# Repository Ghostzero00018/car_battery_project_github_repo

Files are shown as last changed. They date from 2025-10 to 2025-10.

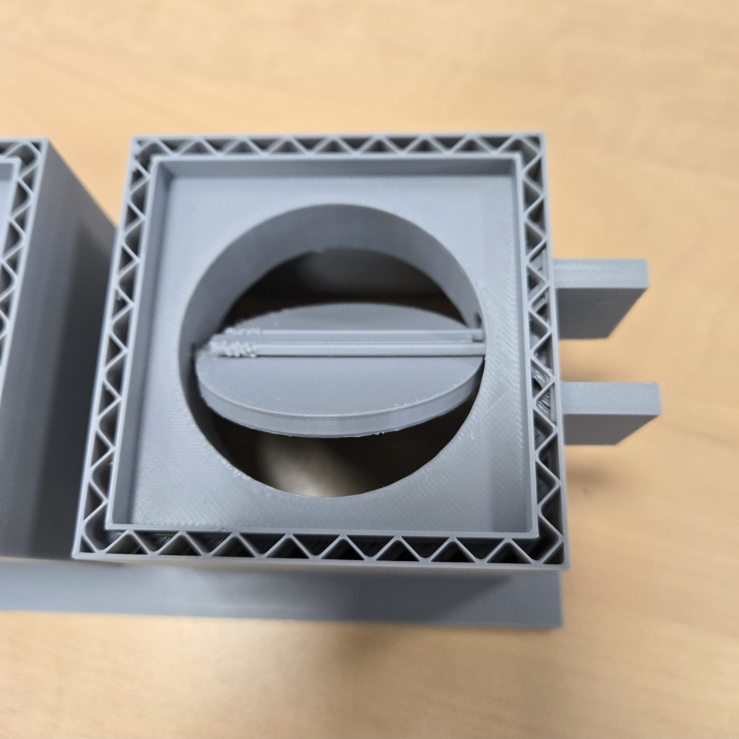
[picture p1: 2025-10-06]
docs/Report/Pics&Figs/Real_3D_print_parts_pics/Valve_system_with_servo_mount.jpg

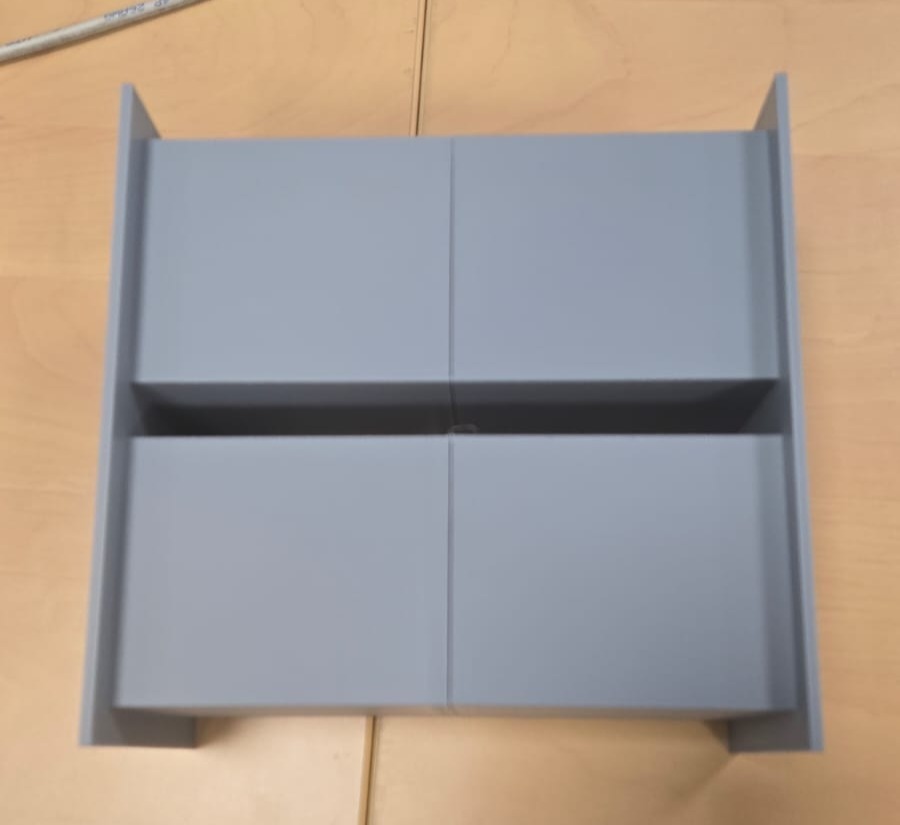
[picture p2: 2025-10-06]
docs/Report/Pics&Figs/Real_3D_print_parts_pics/docking_mechanism.jpg

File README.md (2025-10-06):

# Cascade Temperature Control with Smart Air Flow  

## NOT THE FINAL VERSION

## IMT Nord Europe — DNM–DMI 2025–2026

A compact **thermal control project** combining simulation, control design, and embedded implementation.  
The goal: heat and dry a coated metal plate in a small **8 L hotbox** while keeping air ≤ 70 °C (but higher than 60 °C) for safety.

---

## 🔍 Overview

- **Thermal model:** air, wall, and product (1-D conduction + radiation)  
- **Control:** cascade PI/PID loops  
  - Outer PI: core → air set-point  
  - Inner PID: air → heater power  
- **Airflow system:** fan + valves managed by a smart supervisor (heat-up / hold / safety)  
- **Embedded version:** MicroPython control on **Raspberry Pi Pico W** driving a hobby servo

---

## 🧠 Key Features

- Safe and stable heating control with power/temperature caps  
- Anti-windup, rate-limiting, and derivative filtering  
- Realistic airflow simulation (Δp PI and orifice flow)  
- Ready-to-run **MicroPython demo** — no Wi-Fi required  
- Fully documented **LaTeX report** with cross-references and figures

---

## ⚙️ Hardware Setup

| Component | Role |
|---|---|
| Raspberry Pi Pico W | Controller board |
| Hobby servo (5 V) | Air valve actuator |
| Temperature sensor | Internal ADC or NTC |
| Heater + Fan | Thermal actuation system |

> Servo signal → **GP1**, powered from 5 V (share GND with Pico)

---

## 💻 Quick Start

1. Flash **MicroPython** on the Pico W  
2. Upload `pico_thermostat_servo.py`  
3. Power the servo (5 V + GND) and run the script  
4. Monitor live telemetry

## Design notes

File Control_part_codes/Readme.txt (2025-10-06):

For all the codes in this folder I use Thonny as the IDE to write codes for Raspberry Pi Pico W.

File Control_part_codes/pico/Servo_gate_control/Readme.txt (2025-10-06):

In this folder the codes are mainly focused on the control of the servo, and the servo is used to control the open and close of the gate in this project.
In case you don't know what the gate is for, you can simply consider it as the valve that control whether the air enters the box, and if the air does enter, the air flow rate.
There are 4 versions of the code, each of them are using PID control. You can run on your Raspberry board to see the difference.

To test the code you need some basic hardwares: 1 basic Raspberry board (for example I use Raspberry Pi Pico W in this case, and don't forget about the USB cable so you can connect it to your PC); a breadboard to simplify the wiring; some wires of jumpers; a 5V power source.

The reason I use 5V power source is that if you use the 3.3V voltage that the Raspberry board provided, usually it is not enough to power up even the mini servo motor you can find on the market.

About the detialed wiring, you can check on this link: https://picozero.readthedocs.io/en/latest/recipes.html#servo; pay attention even as shown on the website, probably you still need a 5V power source rather than simply connect the servo to your Raspberry board.

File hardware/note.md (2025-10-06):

# notes.md — Working Notes & Operating Tips

Version: 0.1 (draft)

These notes capture practical tips, gotchas, and short procedures for the **hot-box battery thermal control** prototype.

## NOT THE FINAL VERSION

## 1) Safety First (must-read)

- **Heater fuse & thermal cutoff**: verify correct rating before any test.
- **Never** run the heater unattended on first bring-up. Keep a temp probe + fire extinguisher nearby.
- Ensure **fan spins** before enabling high heater duty. If fan fails, controller should **FAULT** (heater off).
- Keep sensor wiring & tubing away from **hot surfaces** and **12 V power** runs.

---

## 2) Power-On Checklist (short)

1. Visual check: polarity, MOSFET orientation, TVS direction, fuse values.
2. Power rails: 12 V, then 5 V (if used), confirm Pico **3.3 V**.
3. Flash firmware that starts **PWM = 0** and checks sensors.
4. Verify sensors:
   - DS18B20: detect all addresses, read sane values (20–35 °C at room).
   - dP sensor (I²C): show zero-ish Δp with open ports.
5. Fan test: 20% → 50% PWM; confirm airflow & current draw.
6. Heater test: start at 10–20% duty, watch temperature rise & MOSFET case temp.

---

## 3) Quick Calibration Hints

- **DS18B20**: place all sensors together at room temp → record offsets; repeat in warm environment (~40–50 °C).
- **Differential pressure**: with both ports vented together, record zero offset; use short, equal-length tubes.
- **Heater power**: measure 12 V and current with a clamp meter → P ≈ V·I at several PWM levels; note nonlinearity.

---

## 4) Logging & File Hygiene

- Log at least: `time, T_in, T_out, T_surface, PWM_fan, PWM_heater, dP, state, faults`.
- Save runs to `data/yyyy-mm-dd_testname.csv`.  
- Keep large logs out of Git history if they’re huge; consider **Git LFS** or add `data/` to `.gitignore`.

---

## 5) Control Tuning Notes

- Start with **PI** on heater loop; add small **D** only if overshoot persists.
- Use **soft-start**: ramp heater duty over 10–30 s to reduce overshoot.
- If oscillation occurs:
  - Reduce I-gain, add output **slew limit**, or increase fan flow for more **h**.
- Prefer **fixed airflow** for first tests; add supervisory fan control later.

---

## 6) Airflow & Leak Tests

- Prepare **interchangeable orifice inserts** (e.g., Ø2, 3, 4, 6, 8, 10 mm). Label each plate.
- For each orifice size: record steady **Δp**, estimated **Q**, warm-up time, steady power.
- Compare **single-hole + leak** vs **side vent** configurations under the same setpoint.

---

## 7) Common Pitfalls

- **Public repo ≠ write access**: collaborators need to be added on GitHub to push.
- **.gitignore not retroactive**: run `git rm -r --cached .` if you added it late.
- **BLDC fan flyback diode**: don’t add one; use **TVS** on the 12 V rail instead.
- **Noisy sensors** near heater cables: reroute, twist pairs, add small RC at MCU side.

---

## 8) Naming & Units (please stick to these)

- Temperatures: °C; Ambient `T_e`, Air `T_in`, `T_out`, Surface `T_s`.
- Power: W; Duty cycle: 0–100%.
- Pressure: Pa (Δp); Flow: m³/h (log both Δp and PWM; compute Q offline).
- Files: `sim/`, `control/`, `hardware/`, `docs/`, `data/`.

---

## 9) Branch & Changes (lightweight policy)

- Protect `main`; develop on feature branches.
- Use PRs with short descriptions: **why** + **what changed** + **how tested**.
- Tag key milestones (`v0.1-sim`, `v0.2-proto`).

---

## 10) TODO (next steps)

- [ ] Finalize exact Sunon fan P/N and add curve snapshot to `docs/`.
- [ ] Pick dP sensor range (±125 Pa vs ±500 Pa) and wire to I²C.
- [ ] Implement **state machine** (IDLE → PREHEAT → HOLD → FAULT).
- [ ] Add over-temp & sensor-timeout failsafes.
- [ ] Run first **setpoint sweep** (40, 50, 60 °C) and compare with simulation.

---

### Change Log

- **0.1** — Initial working notes added.

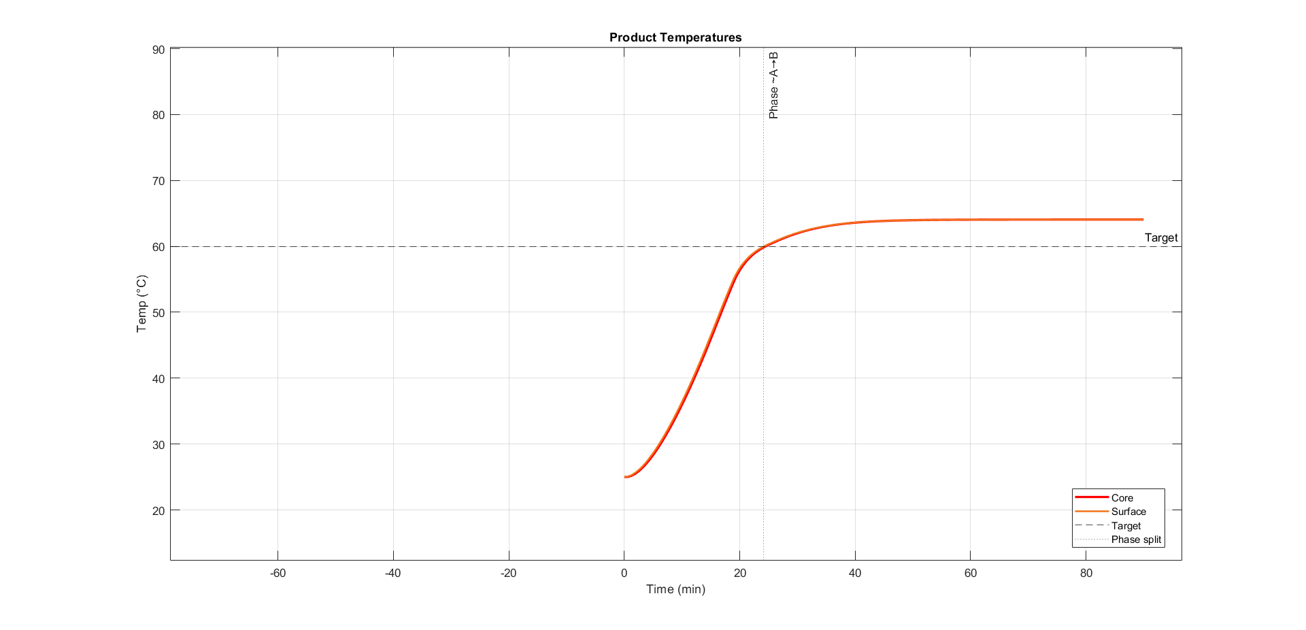
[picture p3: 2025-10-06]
docs/Report/Pics&Figs/Matlab_figs/fig_product_temps.png

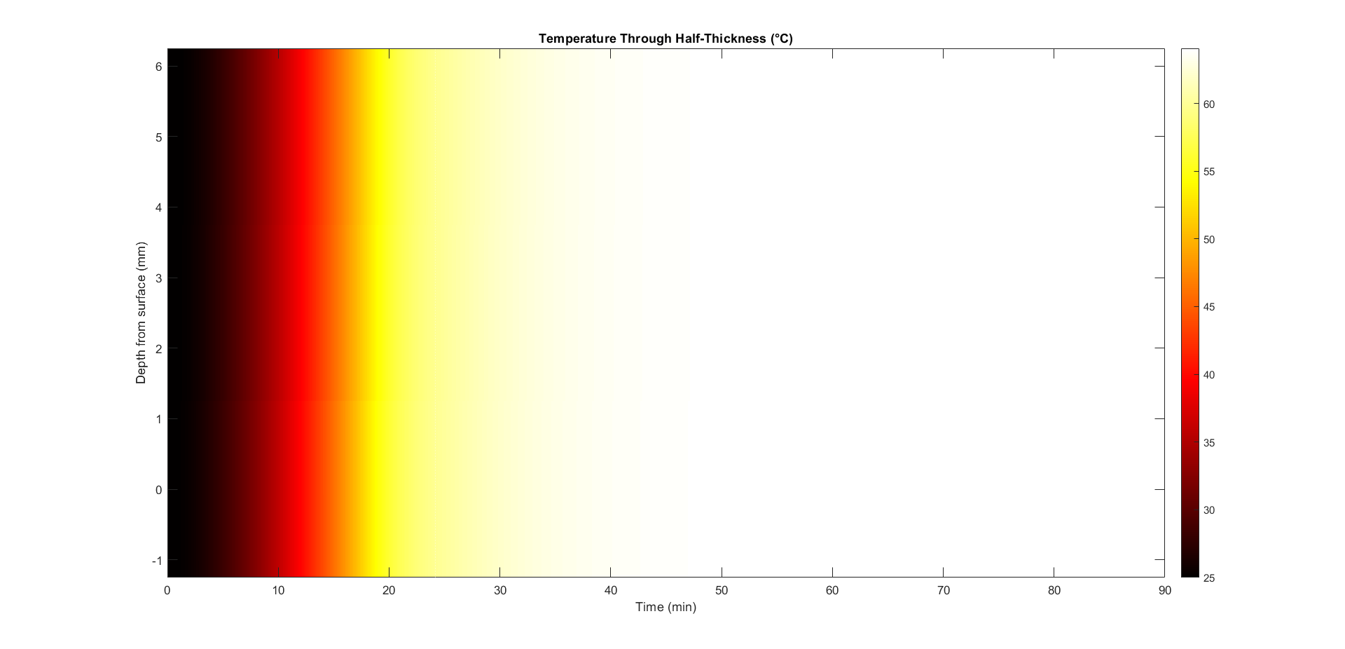
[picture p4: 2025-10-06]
docs/Report/Pics&Figs/Matlab_figs/fig_heatmap.png

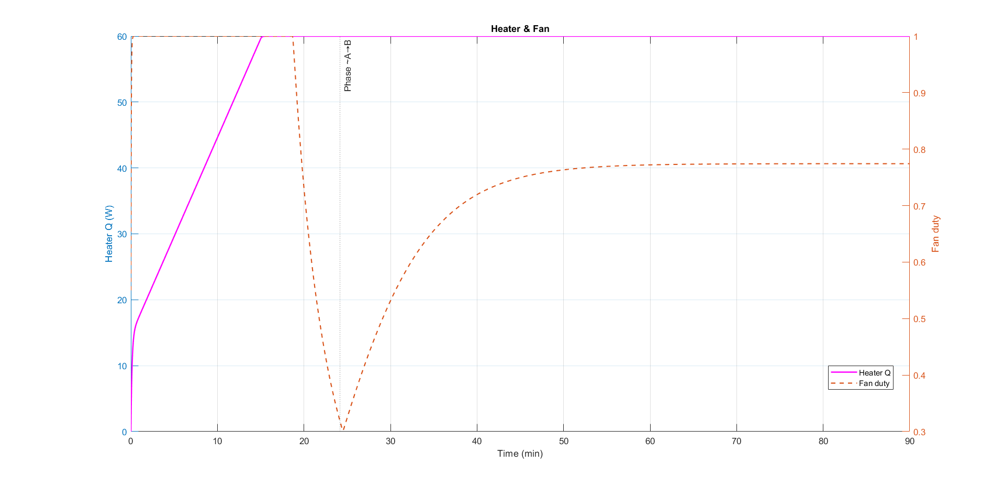
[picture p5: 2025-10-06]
docs/Report/Pics&Figs/Matlab_figs/fig_heater_fan.png

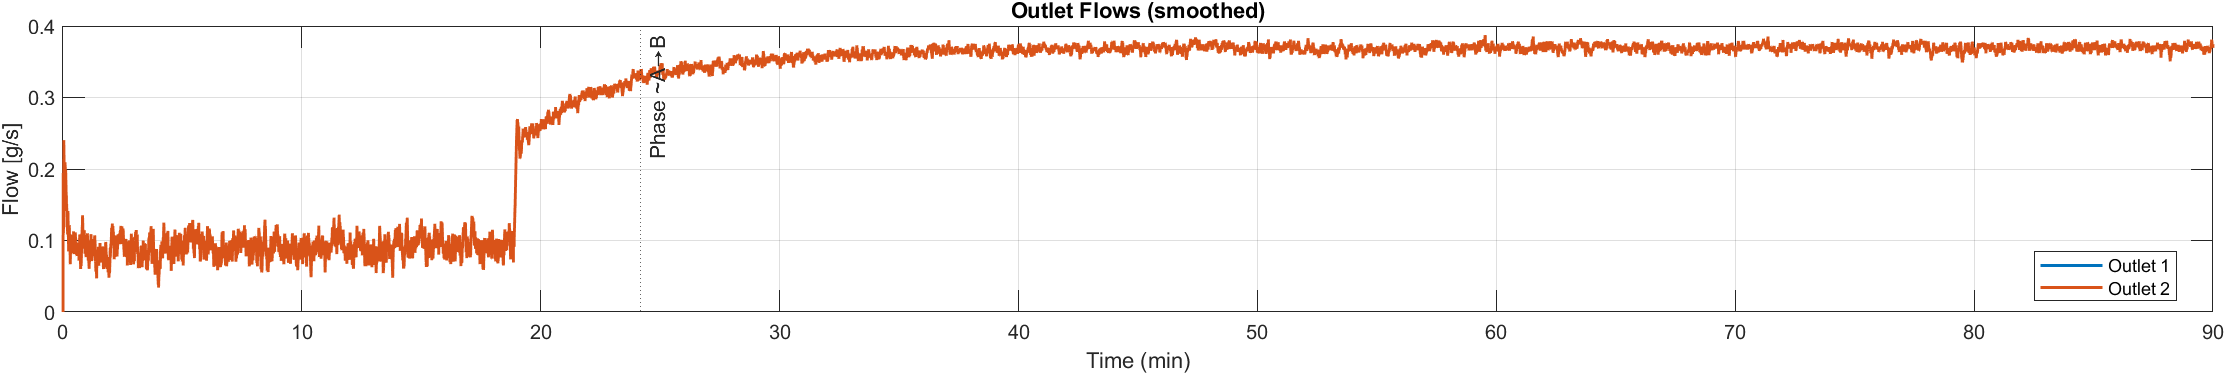
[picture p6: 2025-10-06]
docs/Report/Pics&Figs/Matlab_figs/fig_outlet_flows.png

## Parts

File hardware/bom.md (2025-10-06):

# Possible Bill of Materials (BoM) — Car Battery Thermal Control Prototype

## NOT THE FINAL VERSION

Version: 0.1 (draft)  
Scope: Hot-box prototype for battery thermal conditioning with **Raspberry Pi Pico W** control, **12 V Sunon fan**, heater, and temperature/pressure sensing.

---

## 1) Electronics (Control & Power)

| Group | Qty | Part / Model | Key Specs | Notes |
|---|---:|---|---|---|
| Microcontroller | 1 | **Raspberry Pi Pico W** | RP2040, 2.4 GHz Wi-Fi, 3.3 V I/O | Main controller (PWM fan + heater, sensor IO). Include pin headers if needed. |
| Power Supply | 1 | 12 V DC PSU | ≥ **5 A** (headroom), barrel or screw-terminals | Powers fan + heater (and 5 V/3.3 V rails via buck/USB). Choose higher current if heater >50 W. |
| Buck Converter | 1 | 12 V → 5 V DC-DC | ≥ **2 A**, ripple <50 mV | For sensors/logic if not using Pico’s USB as 5 V source. |
| Heater Switch (MOSFET) | 1 | **IRLZ44N** (logic-level N-MOSFET) or **AOI518**/**AOD510** | V_DS ≥ 30 V, I_D ≥ 30 A, R_DS(on) ≤ 20 mΩ @ 4.5 V | Low-side PWM of heater. Add small heatsink/pad; gate via 100 Ω; include gate-to-GND 100 kΩ. |
| Fan Switch (MOSFET) | 1 | Logic-level N-MOSFET (e.g., **IRLZ44N**) | As above | Low-side PWM enable/speed control for 12 V BLDC fan. |
| TVS Protection | 2 | **SMBJ18A** (or 600 W 18 V SMAJ) | 18 V standoff | Across 12 V rail near fan & heater to clamp transients. |
| Flyback / Snubbers | 0–2 | RC Snubber (optional) | e.g., 100 Ω + 100 nF (X7R) | BLDC fans have internal drivers; avoid diode across fan. Use TVS/snubber on 12 V line if noise observed. |
| Gate Resistor | 2 | 100 Ω | 0.25 W | Between Pico GPIO and each MOSFET gate. |
| Gate Pulldown | 2 | 100 kΩ | 0.25 W | Gate-to-GND, keeps MOSFET off at boot. |
| Current Sense (opt.) | 1 | Low-side shunt + amp (e.g., INA219/INA180) | 0–3 A or per load | For logging heater/fan current. Optional. |
| Fuse | 2 | Blade fuse holders + fuses | **Fan line**: 2 A; **Heater line**: per power | Place on 12 V distribution before each load. |
| Connectors | — | 2-pin/3-pin terminal blocks (5.08 mm), JST-VH/KK | 12 V lines, sensors | Use locking connectors for vibration safety. |
| Wiring | — | 16–20 AWG (power), 24–26 AWG (signals) | Silicone-insulated preferred | Keep power and sensor harness separated to reduce noise. |
| PCB/Proto | 1 | Perfboard or small PCB | — | For MOSFETs, TVS, connectors. Add copper pour for dissipation. |
| Heatsink/Pad | 1–2 | Small TO-220 heatsink + thermal pad | θ_sa ≤ 30 °C/W | For MOSFETs if heater power is high / enclosure warm. |

---

## 2) Actuators (Fan & Heater)

| Group | Qty | Part / Model | Key Specs | Notes |
|---|---:|---|---|---|
| Fan (Primary) | 1 | **Sunon 60×60×38 mm, 12 V** (≈ **96 m³/h**) | BLDC, 10–12 W class | Matches your earlier choice. Verify exact P/N against available stock/curve. |
| Fan Grill + Screws | 1 | 60 mm metal grill + M4 kit | — | Safety + airflow. |
| Heater | 1 | 12–24 V **resistive heater** (cartridge or wirewound) | Power: per simulation (e.g., **50–120 W**); temp rating ≥ 200 °C | Choose voltage to match PSU. If using 24 V heater, supply must be 24 V or use separate PSU. |
| Thermal Fuse | 1 | Non-resettable thermal cutoff | Trip 10–15 °C above max allowed | In series with heater for fail-safe. |
| Thermal Pad/Tape | 1 | High-temp mounting | ≥ 150 °C | For attaching cartridge/wire heater to plate if needed. |

> **Heater sizing**: From sim, ensure ≥30% headroom over steady-state power. Prefer PWM control via MOSFET over linear control.

---

## 3) Sensors

| Group | Qty | Part / Model | Key Specs | Notes |
|---|---:|---|---|---|
| Air Temp (inlet) | 1 | **DS18B20** (digital) or 10 k NTC | −10…85 °C (DS18B20) | DS18B20 (OneWire) simplifies wiring; NTC gives faster response but needs ADC. |
| Air Temp (outlet) | 1 | **DS18B20** or 10 k NTC | As above | For ΔT across box. |
| Battery Surface Temp | 1 | **DS18B20 TO-92** with thermal epoxy **or** NTC epoxied | −10…125 °C | Bond to surface; strain-relief the lead. |
| Differential Pressure | 1 | **Low-range dP sensor** (e.g., **SDP31/SDP810**, Honeywell **ABP** series) | ±125 Pa … ±500 Pa range, I²C/analog | Select range to match expected duct/box Δp; tube barbs required. |
| Ambient Temp (opt.) | 1 | **BME280/HTU21** | T/H (and P) | For ambient compensation and logs. |
| Tubing & Ports | 1 | 3–4 mm ID silicone + panel barbs | — | For dP across orifice/box; keep tubes short and equal. |

**Note:** If you choose NTCs, add: pull-down resistors (e.g., 10 k 1%), filtering (RC), and calibrate beta values.

---

## 4) Enclosure & Mechanics

| Group | Qty | Part / Model | Key Specs | Notes |
|---|---:|---|---|---|
| Hot Box | 1 | Insulated box (DIY or off-the-shelf) | Heat-resistant interior | Must tolerate heater proximity; add standoffs for test article. |
| Orifice / Leak Kit | 1 | Interchangeable inserts (drilled plates) | Ø 2–10 mm set | For **single-hole + leak** tests; label diameters. |
| Cable Glands | 2–4 | M12/M16 | For 3–6 mm cable | Feed-throughs for sensors and power. |
| Standoffs | 4 | Nylon/ceramic | — | Thermal isolation of DUT from walls. |
| Mounting Plate | 1 | Aluminum or FR-4 | — | For heater + temp sensor interface in box. |
| Fan Gasket | 1 | Foam or silicone | — | Reduces recirculation/leaks around fan frame. |

---

## 5) Tools & Consumables (not shipped with design)

- Soldering iron, leaded solder (or lead-free), flux
- Crimp tool (for JST/KK) and assortment of **ferrules**
- Heat-shrink tubing, zip ties, **PTFE** insulated wire for high-temp sections
- Thermal epoxy for sensor bonding
- Multimeter, clamp meter (optional), handheld manometer (optional for dP sanity check)

---

## 6) Electrical Ratings & Budgets (example)

| Load | Voltage | Power / Current | Notes |
|---|---:|---:|---|
| Fan | 12 V | 10–12 W (~0.9 A peak) | Depends on model/PWM. |
| Heater | 12 V | 60 W ⇒ **5 A** (example) | Size to your setpoint/ambient. |
| Pico + Sensors | 5 V | ≤ **300 mA** | Buck from 12 V if not using USB 5 V. |

> **PSU sizing rule**: Sum currents × 1.5 safety factor.

---

## 7) Pico W Pinout (proposed)

| Function | Pico W Pin | Notes |
|---|---|---|
| Heater PWM (MOSFET gate) | **GP15** | With 100 Ω series; 100 kΩ pulldown. |
| Fan PWM (MOSFET gate) | **GP14** | As above. |
| DS18B20 OneWire | **GP4** | 4.7 kΩ pull-up to 3.3 V. |
| I²C (dP sensor) | **GP6 (SDA), GP7 (SCL)** | 4.7 kΩ pull-ups to 3.3 V if needed. |
| Spare ADC (NTC alt.) | **GP26/27/28** | RC filter if long leads. |
| UART (logging, opt.) | **GP0/GP1** | To USB-UART if desired. |
| GND / 3V3 | — | Common grounds between logic and power. |

---

## 8) Part Number Suggestions (fill when ordering)

| Item | Preferred P/N | Alt P/N | Vendor/Link | Status |
|---|---|---|---|---|
| Sunon fan 60×60×38 mm, 12 V | *(fill exact P/N)* | — | — | ☐ |
| Heater (XX W @ YY V) | — | — | — | ☐ |
| dP sensor (±ZZ Pa) | — | — | — | ☐ |
| Pico W | RPI-PICO-W | — | — | ☐ |
| MOSFET (heater) | IRLZ44N | AOI518 / AOD510 | — | ☐ |
| TVS 18 V | SMBJ18A | SMAJ18A | — | ☐ |
| Buck 12→5 V | — | — | — | ☐ |
| DS18B20 (×3) | DS18B20+ | — | — | ☐ |
| Fuse holders + fuses | — | — | — | ☐ |
| Terminal blocks | — | — | — | ☐ |

---

## 9) Safety Notes

- Place a **fuse** on each 12 V branch (fan, heater).  
- Add a **thermal cutoff** in series with the heater.  
- Keep **sensor wiring** away from **heater power** lines; twist pairs for dP tubing if long.  
- Verify **MOSFET temperature** under worst-case duty cycle; heatsink if needed.  
- Use **TVS** on the 12 V rail near loads; avoid flyback diodes across BLDC fans.

---

### Change Log

- **0.1** — Initial draft BoM for simulation prototype.

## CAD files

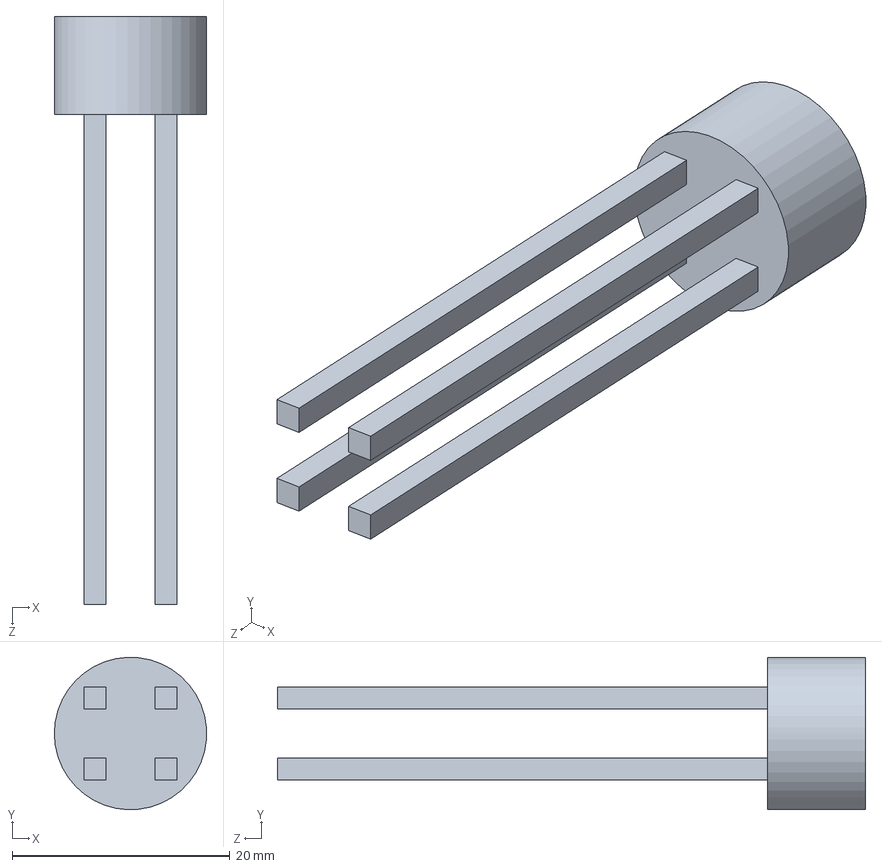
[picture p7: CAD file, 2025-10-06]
Mecanical_structure_solidworks/axis.SLDPRT
14.0 x 14.0 x 54.0 mm

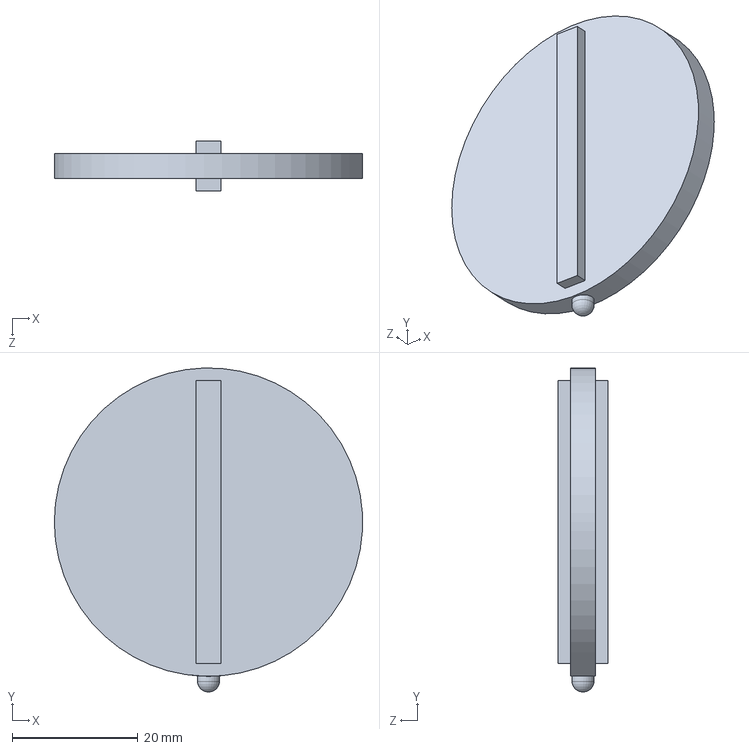
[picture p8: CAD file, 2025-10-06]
Mecanical_structure_solidworks/valve.SLDPRT
49.0 x 51.5 x 8.00 mm

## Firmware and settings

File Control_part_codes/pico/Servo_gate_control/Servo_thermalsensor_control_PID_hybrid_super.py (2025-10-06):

# Pico W — Robust Hybrid Thermostat → Servo (GP1)
# Power servo from 5V, share GND with Pico. No Wi-Fi required.

from machine import Pin, PWM, ADC
import time

# ========= USER SETTINGS =========
# Pins/servo geometry
SERVO_PIN       = 1          # PWM pin to servo signal
SERVO_FREQ_HZ   = 50         # hobby servos use ~50 Hz
CLOSED_US       = 1000       # ~0°
OPEN_US         = 2000       # ~180°
REVERSED        = False      # True to invert motion

# Temp thresholds (°C)
T_LOW           = 18.0       # ≤ T_LOW  → fully CLOSED
T_HIGH          = 22.0       # ≥ T_HIGH → fully OPEN

# Robustness
TEMP_ALPHA      = 0.25       # EMA smoothing for temperature (0..1)
EDGE_HYST       = 0.5        # extra °C stickiness at edges (anti-chatter)
DEADBAND_US     = 6          # ignore tiny pulse changes ≤ this
RAMP_US_PER_S   = 400        # limit speed (µs per second) for gentle motion
WARMUP_S        = 2.0        # ignore first seconds to stabilize ADC

# Loop timing & telemetry
UPDATE_HZ       = 10         # control loop rate
PRINT_EVERY_S   = 1.0        # telemetry interval

# Simple temperature calibration (optional)
TEMP_OFFSET_C   = 0.0        # add after conversion
TEMP_SCALE      = 1.0        # multiply after offset
# =================================


# ---- Low-level helpers ----
def clamp(v, lo, hi):
    return lo if v < lo else hi if v > hi else v

def lerp(a, b, x):
    return a + (b - a) * x


# ---- Servo setup ----
servo = PWM(Pin(SERVO_PIN))
servo.freq(SERVO_FREQ_HZ)
_period_us = 1_000_000 // SERVO_FREQ_HZ  # 20_000 for 50 Hz

def _apply_reverse(us):
    if not REVERSED:
        return us
    # Mirror around mid
    mid = (CLOSED_US + OPEN_US) // 2
    return mid - (us - mid)

def write_us(us):
    us = clamp(us, min(CLOSED_US, OPEN_US), max(CLOSED_US, OPEN_US))
    us = _apply_reverse(us)
    servo.duty_u16(int(us * 65535 // _period_us))


# ---- Temperature (internal sensor on ADC4) ----
adc = ADC(4)
VREF, ADC_MAX = 3.3, 65535

def read_temp_c_raw():
    v = adc.read_u16() * VREF / ADC_MAX
    # RP2040 formula: T = 27 - (V - 0.706) / 0.001721
    return 27.0 - (v - 0.706) / 0.001721

def read_temp_c():
    t = read_temp_c_raw()
    t = (t + TEMP_OFFSET_C) * TEMP_SCALE
    return t


# ---- Hybrid mapping with hysteresis & smoothing ----
def temp_to_target_us(t):
    # Add a small hysteresis band around edges
    if t <= (T_LOW - EDGE_HYST):
        return CLOSED_US
    if t >= (T_HIGH + EDGE_HYST):
        return OPEN_US
    # Proportional zone between thresholds (clamped to [0..1])
    x = clamp((t - T_LOW) / (T_HIGH - T_LOW), 0.0, 1.0)
    return int(lerp(CLOSED_US, OPEN_US, x))


# ---- Main control loop ----
dt = 1.0 / UPDATE_HZ
failsafe = (CLOSED_US + OPEN_US) // 2
tele_next = time.ticks_ms()

print("Hybrid thermostat (robust) running. Ctrl+C to stop.")
# Warmup + initial temperature EMA
t_avg = read_temp_c()
write_us(failsafe)

# Warm-up period (optional)
t0 = time.ticks_ms()
while (time.ticks_ms() - t0) < int(WARMUP_S * 1000):
    t_avg = TEMP_ALPHA * read_temp_c() + (1.0 - TEMP_ALPHA) * t_avg
    time.sleep(0.05)

# Start at mapped target
current_us = temp_to_target_us(t_avg)
write_us(current_us)

try:
    while True:
        loop_start = time.ticks_ms()

        # Read & smooth temperature
        t_now = read_temp_c()
        t_avg = TEMP_ALPHA * t_now + (1.0 - TEMP_ALPHA) * t_avg

        # Compute target and limit slew rate
        target_us = temp_to_target_us(t_avg)
        max_step = int(RAMP_US_PER_S * dt)
        if target_us > current_us + max_step:
            target_us = current_us + max_step
        elif target_us < current_us - max_step:
            target_us = current_us - max_step

        # Deadband to reduce unnecessary writes
        if abs(target_us - current_us) > DEADBAND_US:
            write_us(target_us)
            current_us = target_us

        # Periodic telemetry
        if time.ticks_diff(time.ticks_ms(), tele_next) >= 0:
            print(f"T={t_avg:5.2f} °C  pulse={current_us} us  "
                  f"zone={'CLOSED' if current_us<=CLOSED_US else 'OPEN' if current_us>=OPEN_US else 'MIX'}")
            tele_next = time.ticks_add(tele_next, int(PRINT_EVERY_S * 1000))

        # Pace the loop
        elapsed = time.ticks_diff(time.ticks_ms(), loop_start) / 1000.0
        sleep_left = dt - elapsed
        if sleep_left > 0:
            time.sleep(sleep_left)

except KeyboardInterrupt:
    pass
finally:
    servo.deinit()
    print("Stopped.")

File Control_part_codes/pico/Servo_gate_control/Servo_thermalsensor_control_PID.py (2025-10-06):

# Proportional-only temperature → servo control
# Servo signal: GP1 (PWM-capable). Servo power: 5V, shared GND with Pico W.

from machine import Pin, PWM, ADC
import time

# ===== Hardware =====
SERVO_PIN = 1
pwm = PWM(Pin(SERVO_PIN))
pwm.freq(50)   # 50 Hz standard for hobby servos

MIN_US, MAX_US = 1000, 2000   # servo range (0°..180° approx)

def write_us(us):
    pwm.duty_u16(int(us * 65535 / 20000))  # 20 ms period

# ===== Internal temp sensor =====
adc = ADC(4)
VREF = 3.3
ADC_MAX = 65535

def read_temp_c():
    v = adc.read_u16() * VREF / ADC_MAX
    return 27.0 - (v - 0.706) / 0.001721

# ===== Control params =====
SETPOINT = 30.0    # target temperature °C
Kp = 30.0          # proportional gain (servo µs per °C error)
DEADBAND = 5       # µs: ignore tiny changes to avoid jitter
UPDATE_PERIOD = 0.5  # seconds

# ===== Main loop =====
print("Proportional control running. Ctrl+C to stop.")
try:
    while True:
        temp = read_temp_c()
        error = SETPOINT - temp  # positive = too cold

        # Proportional output (center at midpoint)
        midpoint = (MIN_US + MAX_US) // 2
        pulse = int(midpoint + Kp * error)

        # Clamp to safe range
        pulse = max(MIN_US, min(MAX_US, pulse))

        # Deadband filter
        if abs(pulse - midpoint) > DEADBAND:
            write_us(pulse)

        print(f"T={temp:5.2f} °C  err={error:+5.2f}  pulse={pulse} us")
        time.sleep(UPDATE_PERIOD)

except KeyboardInterrupt:
    pass
finally:
    pwm.deinit()
    print("Stopped.")

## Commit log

2025-09-24 add some Raspberry files
2025-09-24 Add initial Bill of Materials (BoM) for Car Battery Thermal Control Prototype
2025-09-24 Add initial working notes and operating tips for hot-box battery thermal control prototype
2025-09-24 Add ULTIMATE_OVEN_8L_FINAL_SMOOTH.m for advanced thermal simulation with PID control
    - Implemented a comprehensive thermal model for an 8L oven including air-loop PID control, battery heat conduction, and radiation effects.
    - Integrated actuator dynamics with rate limits for heater power and airflow.
    - Developed a detailed control strategy with anti-windup mechanisms and setpoint smoothing.
    - Included visualization features for 3D oven representation and temperature profiling through battery layers.
    - Added extensive comments and documentation for clarity and future reference.
2025-10-06 Add ULTIMATE_OVEN_8L_SEPARATE_SIM.m for 8L oven simulation with detailed control and thermal dynamics
    - Implemented continuous phase blend with stable hold and wall losses
    - Configured slow warm-up preset with soft-start and air inertia
    - Defined tunable parameters for temperature control and air dynamics
    - Developed ODE for oven dynamics including air, product, and wall interactions
    - Added visualization for product temperatures, air control, heater and fan dynamics, flow rates, and power balance
    - Included calibration helpers for valve area and heat transfer coefficients
2025-10-06 Add ULTIMATE_OVEN_8L_FINAL_SMOOTH.m for advanced thermal simulation with PID control
    - Implemented a comprehensive thermal model for an 8 L oven with a focus on battery heating.
    - Included detailed physical parameters, control strategies, and safety measures.
    - Developed a PID control system for air and heater management, with anti-windup and slew-rate limits.
    - Added visualization features for 3D representation of the oven and temperature distribution.
    - Integrated ODE solver for dynamic simulation of temperature changes over time.
2025-10-06 Add ULTIMATE_OVEN_8L_FINAL_SMOOTH.m for advanced thermal simulation with PID control
    - Introduced detailed physical parameters for air, battery, and wall properties.
    - Developed a time-stepping solver using ODE15s to simulate temperature dynamics over time.
    - Included control logic for heater power and airflow with anti-windup and rate-limiting features.
    - Added visualization capabilities for 3D oven representation and temperature distribution through battery layers.
    - Provided console output for simulation results and performance metrics.
    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
2025-10-06 Add comprehensive research paper on heating and drying in an 8-L insulated box
2025-10-06 Implement code changes to enhance functionality and improve performance
    [axis.SLDPRT, valve.SLDPRT]
2025-10-06 Enhance Pico W hybrid thermostat code with improved comments, structure, and optional warm-up period
2025-10-06 Implement robust hybrid thermostat with enhanced control features and temperature smoothing
2025-10-06 Add README file to document the use of Thonny IDE for Raspberry Pi Pico W code development
2025-10-06 Add initial README file for servo gate control project
2025-10-06 Update README to include detailed testing requirements and wiring information for servo control project
2025-10-06 Update README to clarify power requirements and wiring for servo control
2025-10-06 Update BoM and notes to clarify document status and improve readability
2025-10-06 Add clarification to BoM document status
2025-10-06 Add ULTIMATE_OVEN_8L_SEPARATE_SIM.m for 8L oven simulation with detailed control and calibration features
    - Implemented continuous phase blend and stable hold with wall losses
    - Configured soft-start parameters for slower warm-up
    - Defined geometry and physics parameters for the oven simulation
    - Established control strategies for heater, air temperature, and purge management
    - Included detailed plotting functions for temperature, flow rates, and power balance
    - Added calibration helpers for optimizing valve area and heat transfer coefficients
2025-10-06 Clarify temperature safety range in project goal description
2025-10-06 Fix typos and improve clarity in README files for servo control and MATLAB simulation
2025-10-12 Add wiring diagram image for servo gate control
